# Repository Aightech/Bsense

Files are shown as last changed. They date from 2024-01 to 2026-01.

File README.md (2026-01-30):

# Bsense

Simple device to trigger audio and haptic stimuli for prenatal studies.

## Hardware

### Components

| Part | Qty | Price | Link |
|---|-----|---|---|
| Teensy 4.0/4.1 | 1 | £25 | [PJRC](https://www.pjrc.com/store/teensy40.html) |
| H-bridge (L298N) | 1 | £2 | [Amazon UK](https://www.amazon.co.uk/Driver-H-Bridge-Stepper-Controller-Arduino/dp/B07YC1GFM3) |
| LRA (VG0640001D) | 1 | £2 | [Digi-Key](https://www.digikey.co.uk/en/products/detail/vybronics-inc/VG0640001D/15220805) |
| LRA (VLV101040A) | 1 | £5 | [Digi-Key](https://www.digikey.co.uk/en/products/detail/vybronics-inc/VLV101040A/12323590) |
| STSPIN250 dev board | 1 | £15 | [MikroElektronika](https://www.mikroe.com/stspin250-click) |
| Buzzer | 1 | £5 | [Amazon UK](https://www.amazon.co.uk/dp/B096ZWCG7F) |
| GX16-5 connector | 5 | £1.50 | [Amazon UK](https://www.amazon.co.uk/gp/product/B07WPBXX57) |
| USB-B connector | 1 | £6.50 | [Amazon UK](https://www.amazon.co.uk/gp/product/B075FVGH8H/) |

**Total cost:** ~£70

### Schematic

System schematic

### Enclosure

| Model  | File |
|---|---|
| Box | [docs/box.stl](docs/box.stl) |
| Lid | [docs/lid.stl](docs/lid.stl) |

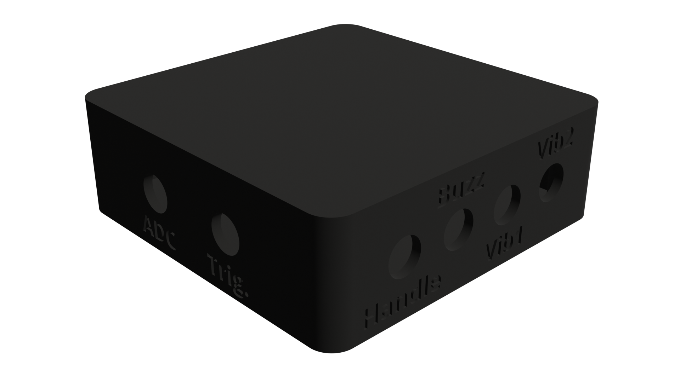
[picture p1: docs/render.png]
Rendered enclosure


## Software

### Installation

**Option 1: Download pre-built executable**

Download from [GitHub Releases](../../releases) - available for Windows, macOS, and Linux.

**Option 2: Run from source**

```bash
# Clone and setup
git clone https://github.com/your-repo/bsense.git
cd bsense/app/python

# Create virtual environment
python3 -m venv bsense_env
source bsense_env/bin/activate  # Linux/macOS
# bsense_env\Scripts\activate   # Windows

# Install dependencies
pip install -r requirements.txt

# Run
python main.py
```

CLI flags:
- `-d` - Debug mode
- `-p <port>` - Serial port (e.g., `/dev/ttyACM0` or `COM3`)
- `-f <file>` - Load experiment JSON file

### Usage

1. **Connect**: Enter serial port, click **Connect**
2. **Validate subject**: Input subject ID, click ✔
3. **Select protocol**: Choose from dropdown or browse JSON file
4. **Run**: Click ▶ to start, ‖ to pause, ■ to stop
5. **Log**: View live log; add manual annotations via input field

### Building Executables

```bash
cd app/python
./build.sh        # Linux/macOS
build.bat         # Windows
```

Or use GitHub Actions: push a tag (`git tag v1.0.0 && git push --tags`) to automatically build for all platforms.

## Experiment Protocol (JSON)

For detailed protocol documentation, see [userManualGUI.md](userManualGUI.md).

Protocols are **case-insensitive** - `"type": "sequence"` works the same as `"Type": "Sequence"`.

### Rule Types

| Type | Description | Required Fields |
|---|---|---|
| `Sequence` | Repeatable block | `Repeat`, `Content` |
| `stimulus` | Container for stimuli | `Content` (list) |
| `Delay` | Pause between stimuli | `Duration` (seconds) |
| `Dropout_sequence` | Random omissions | `Repeat`, `Number_drop`, `Content`, `Dropout_content` |
| `Randomized_sequence` | Shuffled stimuli with constraints | `Max_consecutive`, `Stimuli` |

### Stimulus Types

| Type | Description | Required Fields |
|---|---|---|
| `Vib1` | Vibration motor | `Amplitude` (0-1), `Frequency` (Hz), `Duration` (ms) |
| `Buzzer` | Audio tone | `Amplitude` (0-1), `Tone` (Hz), `Duration` (ms) |
| `BuzzVib1` | Combined | `Amplitude_vib1`, `Frequency_vib1`, `Duration_vib1`, `Amplitude_buzz`, `Tone_buzz`, `Duration_buzz` |

### Example Configs

See `app/python/config/` for examples:

| File | Description |
|---|---|
| `example_vibration.json` | Basic vibration sequence |
| `example_buzzer.json` | Buzzer tone sequence |
| `example_combined.json` | Simultaneous vib + buzzer |
| `example_dropout.json` | Sequence with random dropouts |
| `example_randomized.json` | Randomized intensity levels |

### Randomized Sequence Example

For counterbalanced experiments with multiple intensity levels:

```json
{
    "Type": "Randomized_sequence",
    "Max_consecutive": 3,
    "Delay": {"Type": "Delay", "Duration": 2, "Deviation": 0.5},
    "Stimuli": [
        {"Repeat": 20, "Label": "Low", "Content": {"Type": "Vib1", "Amplitude": 0.33, "Frequency": 170, "Duration": 100}},
        {"Repeat": 20, "Label": "Medium", "Content": {"Type": "Vib1", "Amplitude": 0.66, "Frequency": 170, "Duration": 100}},
        {"Repeat": 20, "Label": "High", "Content": {"Type": "Vib1", "Amplitude": 1.0, "Frequency": 170, "Duration": 100}}
    ]
}
```

This creates 60 stimuli (20 × 3 levels), randomized with no intensity appearing more than 3 times consecutively.

## Serial Protocol

Binary protocol at 115200 baud:

```
[0xaa] [cmd] [len] [payload...]
```

| Command | Payload (bytes) | Description |
|---|---|---|
| `'v'` | amp:1, freq:2, dur:2 | Vibration 1 |
| `'b'` | amp:1, freq:2, dur:2 | Buzzer |
| `'c'` | ampV:1, freqV:2, durV:2, ampB:1, freqB:2, durB:2 | Combined |

- Amplitude: 0-255 (0.0-1.0 scaled)
- Frequency: uint16 little-endian (0-65535 Hz)
- Duration: uint16 little-endian (milliseconds)

### MATLAB Example

```matlab
port = "COM3";
s = serialport(port, 115200);
flush(s);

START_CHAR = uint8(hex2dec('aa'));

function sendVib1(s, amp, freq, duration)
    % amp: 0-255, freq: Hz (uint16), duration: ms (uint16)
    payload = [uint8(amp), typecast(uint16(freq), 'uint8'), typecast(uint16(duration), 'uint8')];
    header = [START_CHAR; uint8('v'); uint8(numel(payload))];
    write(s, [header, payload], 'uint8');
end

function sendBuzz(s, amp, freq, duration)
    payload = [uint8(amp), typecast(uint16(freq), 'uint8'), typecast(uint16(duration), 'uint8')];
    header = [START_CHAR; uint8('b'); uint8(numel(payload))];
    write(s, [header, payload], 'uint8');
end

% Examples:
% sendVib1(s, 128, 170, 500);   % vibration: 170 Hz, 500 ms
% sendBuzz(s, 200, 1000, 250);  % buzzer: 1 kHz, 250 ms
```

## Firmware

Located in `code/teensyScript/`. Flash using Arduino IDE or PlatformIO with Teensy board support.

**Note:** LRA actuator is rated 1.8V. With 3.3V Teensy output, saturation occurs at ~60% duty cycle. Effective amplitude range is 0-77 (of 0-255).

## Technical Documentation

### Signal Generation

See [reports/siggen.md](reports/siggen.md) for details on PWM-based LRA excitation:
- Amplitude control via PWM duty cycle (0-50% maps to 0-100% user range)
- Frequency-dependent response due to LRA mechanical resonance (~230 Hz)
- Duration control in milliseconds

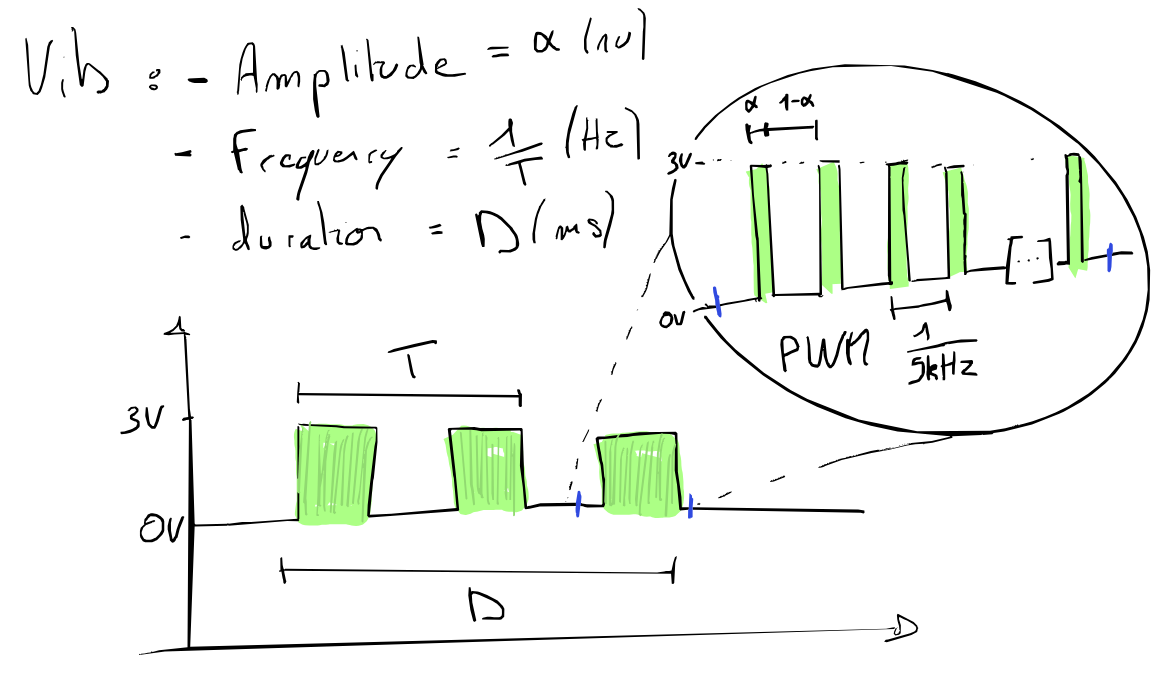
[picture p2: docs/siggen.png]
Signal generation


### LRA Simulation

The `simulation/` folder contains Python tools for modeling LRA response:

```bash
cd simulation
python cmd.py  # Interactive PWM → LRA resonator plot
```

Requires: `numpy`, `matplotlib`, optionally `scipy`

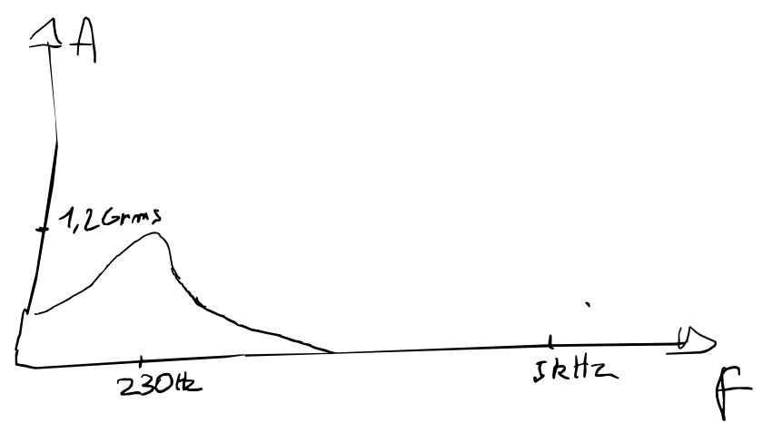
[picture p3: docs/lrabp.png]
LRA band-pass response


### Research Reports

| Report | Description |
|---|---|
| [R05jan25.md](reports/R05jan25.md) | EEG noise testing, amplitude mapping, silicone moulding |
| [siggen.md](reports/siggen.md) | Signal generation and parameter encoding |

## Running Tests

```bash
cd app/python
python -m unittest discover tests/
```

## Changelog

### v1.1.0 (2026-01-30)
- **Randomized_sequence**: New rule type for counterbalanced experiments with `Max_consecutive` constraint
- **Case-insensitive protocol**: JSON field names and types now accept any case
- **Cross-platform builds**: GitHub Actions workflow for Windows, macOS, and Linux executables
- **Improved connection handling**: Better disconnection detection and UI recovery on reconnect
- **Firmware updates**: Hardware PWM for buzzer (better high-frequency performance), 16-bit frequency support
- **Config reorganization**: Clearer example files (`example_*.json`)

### v1.0.0
- Initial release with basic vibration and buzzer control
- Sequence, Delay, and Dropout_sequence rule types

## License

MIT

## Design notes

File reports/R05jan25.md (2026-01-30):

# Report

* **Date:** January 25, 2024
* **Location:** UCL
* **Participants:** Alexis, Tabitha

## Objectives

* Investigate and mitigate EEG noise caused by LRA-related EMI.
* Test actuator amplitude mapping.
* Discuss silicone moulding setup and process.

---

## Activities

### 1. EEG Noise Testing

#### Setup

* At the hospital, Tabitha set up the EEG system with electrodes immersed in a saline solution.
* The Bsense device was configured to send periodic impulses to the LRA actuators.
* Two experimental conditions were tested:

  1. LRA actuators positioned close to the EEG electrodes (≈2–3 cm), without direct contact with the saline solution.
  2. LRA actuators in direct contact with the saline solution.

#### Observations

* **Condition 1 (LRA close, no contact):**
  No visible noise was observed on the EEG signals when the LRA actuators were activated.
* **Condition 2 (LRA in contact with saline):**
  Significant noise appeared on the EEG signals during LRA activation.

#### Hypothesis

* The observed EEG noise is likely caused by direct electrical coupling between the LRA metal casing and the conductive medium (saline / body), rather than radiated EMI.

#### Actions Taken

* **Shielding:** Although shielding did not appear to be the primary issue, the LRA metal casing was connected to a grounded shielding wire as a precautionary measure.

#### Next Steps

* Test the system on-body with the shielding connection in place.
* If noise persists, electrically isolate the LRA casing from the skin using a non-conductive layer (e.g. tape).
* If insulation resolves the issue, design a dedicated non-conductive enclosure for the LRA actuators.

---

### 2. Amplitude Mapping

#### Setup

* Connected the Bsense device to a PC via serial.
* Used a Python script to sweep PWM duty cycle values sent to the LRA actuators.
* Assessed resulting vibration amplitude using a finger as a subjective proxy.

#### Observations

* Above approximately **0.5 duty cycle**, no perceptible increase in vibration amplitude was observed.

#### Actions Taken

* Documented the signal generation and amplitude mapping process (see [LRA_Signal_Generation.md](../docs/LRA_Signal_Generation.md)).
* Created a simulation of the LRA response as a function of PWM duty cycle and excitation frequency.
  The model predicts a linear relationship between duty cycle and vibration amplitude (see figures below).

| Simulation Result                          |
| ------------------------------------------ |
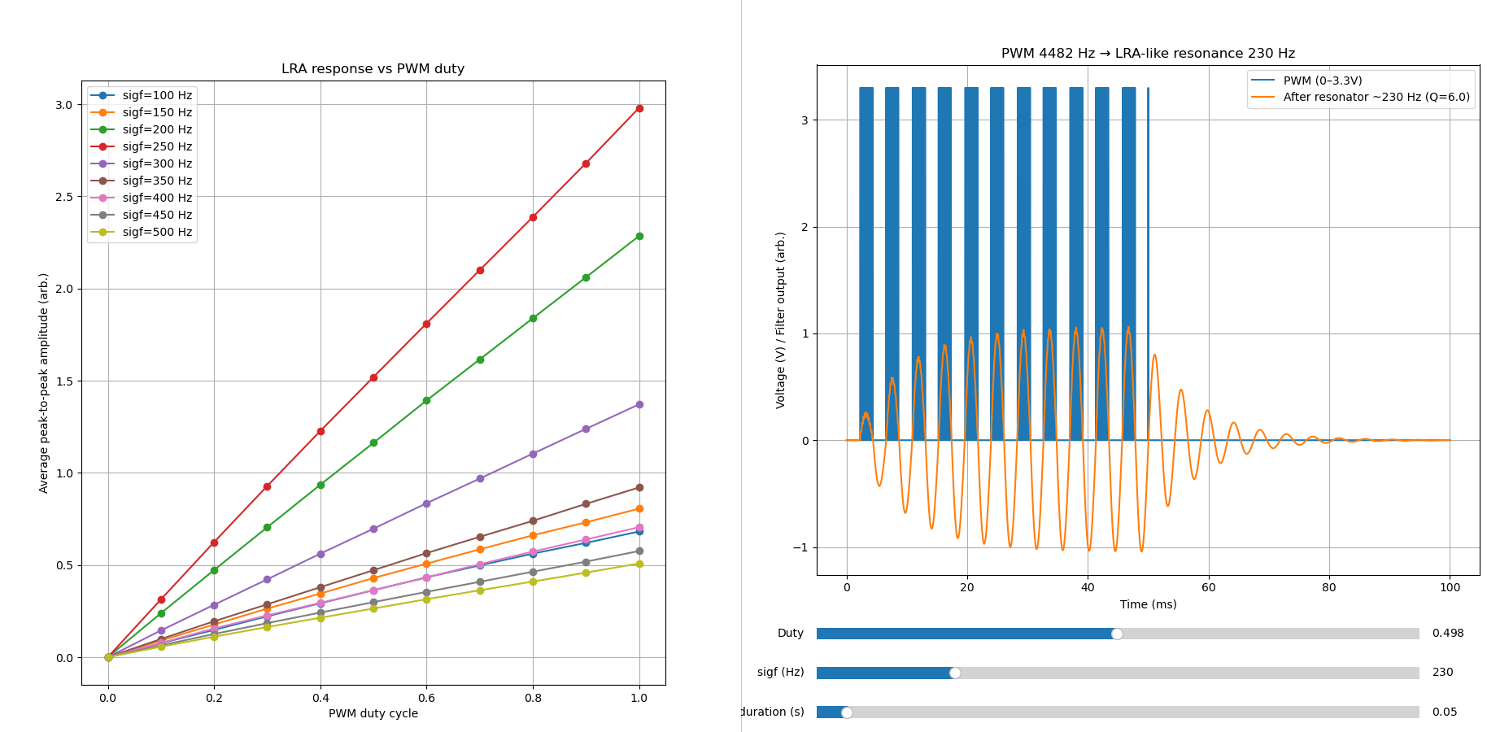
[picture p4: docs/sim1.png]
|  |
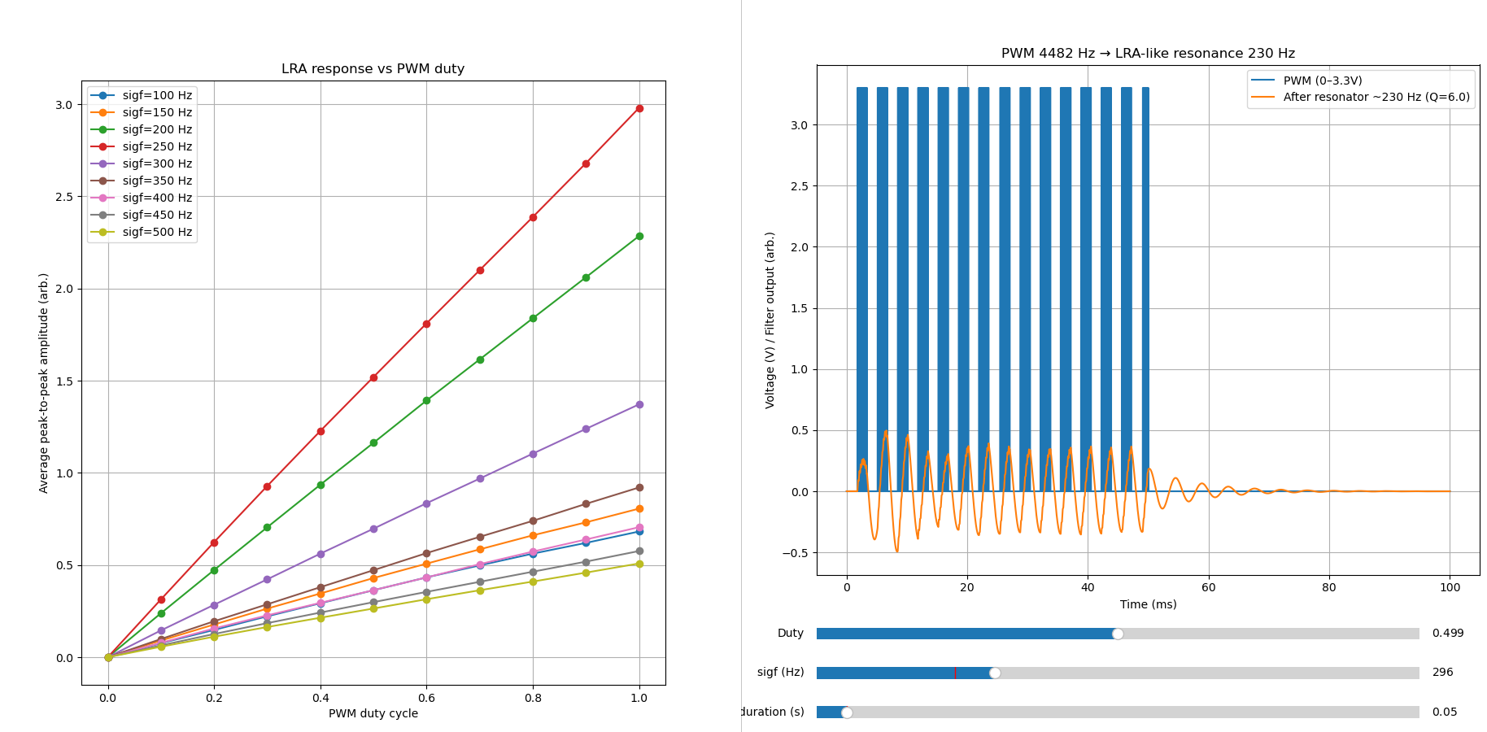
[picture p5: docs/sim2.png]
|  |
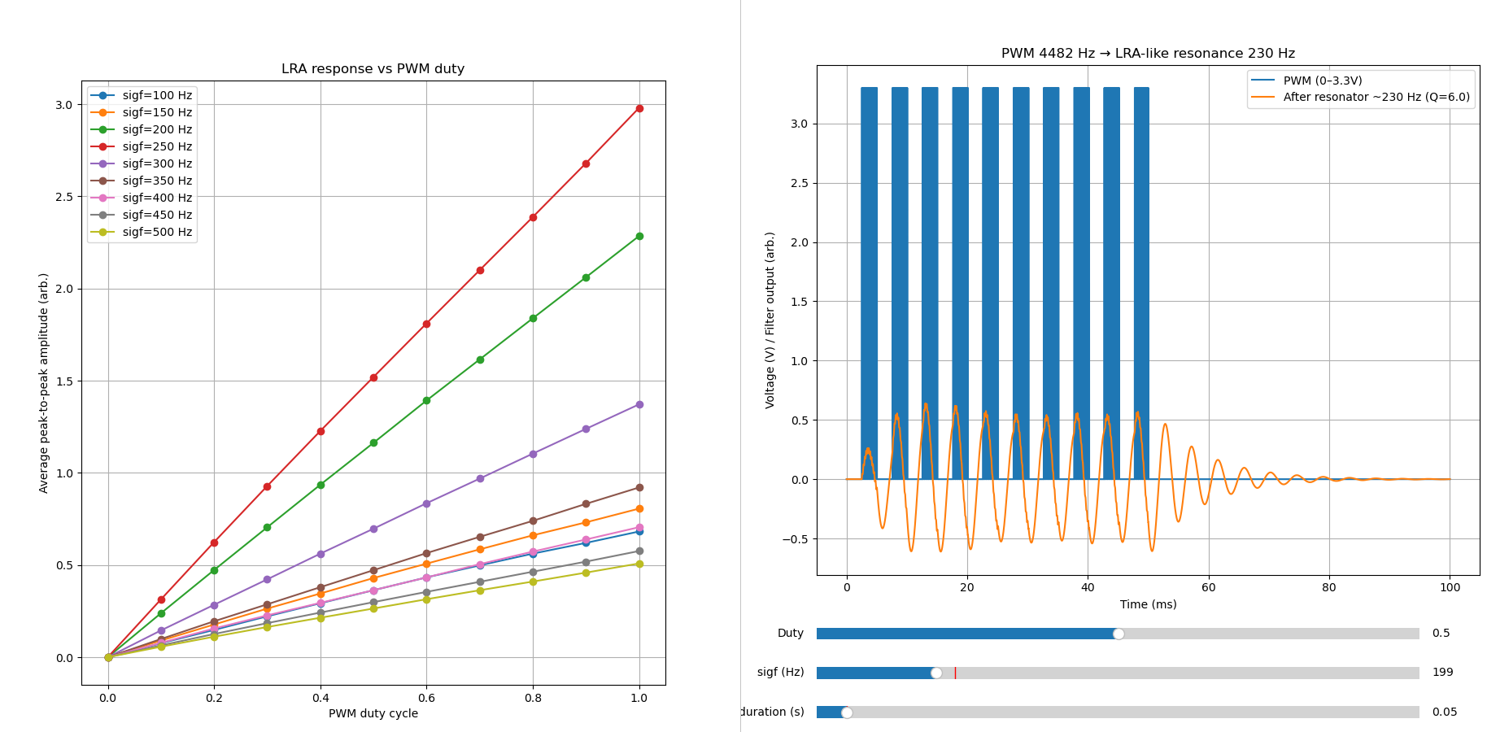
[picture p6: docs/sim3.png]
|  |

* Given the actuator’s **1.8 V RMS rating** and a **3.3 V supply**, maximum usable amplitude is expected around **~70% duty cycle**; beyond this, saturation is likely.
* Firmware was updated (no PC-side changes required) so that the full user-facing duty cycle range (0–100%) maps internally to **0–50% actuator duty cycle**.
* PWM frequency was increased to **46.875 kHz**.

#### Next Steps

* Validate the amplitude mapping using an objective measurement setup (test bench with accelerometer).

---

### 3. Silicone Moulding Discussion

Discussed the silicone moulding workflow for the grasping sensor with Tabitha.

#### Process

1. Mix silicone components A and B thoroughly (1:1 ratio).
2. *(Optional)* Apply a thin layer of release agent (e.g. Vaseline) to the 3D-printed mould to facilitate demoulding.
3. Pour the silicone mixture into the mould.
4. *(Optional)* Degas in a vacuum chamber to remove air bubbles introduced during mixing (recommended but not strictly required).
5. Allow to cure at room temperature for **4–6 hours**.
6. Carefully demould the cured silicone part.

#### Next Steps

* Purchase silicone: [Smooth-On Ecoflex 00-30](https://www.benam.co.uk/ecoflex-00-30).
* 3D print moulds for the sensor components.

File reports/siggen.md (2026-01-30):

# Tap Impulse Generation

Tap impulses are generated by driving the LRA using a parametrised PWM-based excitation signal. The impulse is fully defined by three parameters: **frequency**, **amplitude**, and **duration**.

PWM Signal

---

## Parameters

### Amplitude

* Defines the effective drive amplitude applied to the LRA.
* As the microcontroller cannot output a true analog voltage, amplitude control is implemented using **PWM (Pulse Width Modulation)**.
* The user-facing amplitude parameter is normalised to the range **0–1**.
* Internally, this value maps to a **PWM duty cycle of 0–50%**, ensuring the actuator remains within its safe operating voltage range.

---

### Frequency

* Defines the excitation frequency (in **Hz**) of the signal driving the LRA.
* Vibration strength increases as the excitation frequency approaches the LRA’s mechanical resonance (≈ **230 Hz**).
* Frequencies far from resonance result in significantly reduced vibration amplitude due to the LRA’s band-pass mechanical response.

---

### Duration

* Defines the length of the impulse in **milliseconds**.
* The actuator is driven continuously at the specified frequency and amplitude for the duration of the impulse.

LRA band-pass response

---

## Parameter Encoding

Each parameter is encoded using **1 byte (8 bits)**, allowing compact transmission and deterministic decoding:

* **Frequency:**

  * Range: **0–255 Hz**
  * Resolution: **1 Hz per step**

* **Amplitude:**

  * Range: **0–1 (normalised)**
  * Resolution: **1 / 255 ≈ 0.00392 per step**

* **Duration:**

  * Range: **0–255 ms**
  * Resolution: **1 ms per step**

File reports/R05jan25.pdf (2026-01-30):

# Report

Date: January 25, 2024
Location: UCL
Participants: Alexis, Tabitha

# Objectives

Investigate and mitigate EEG noise caused by LRA-related EMI. Test actuator amplitude mapping.
Discuss silicone moulding setup and process.

# Activities

## 1. EEG Noise Testing

### Setup

At the hospital, Tabitha set up the EEG system with electrodes immersed in a saline solution. The Bsense device was configured to send periodic impulses to the LRA actuators.
Two experimental conditions were tested:
i. LRA actuators positioned close to the EEG electrodes (≈2–3 cm), without direct contact with the saline solution.
ii. LRA actuators in direct contact with the saline solution.

### Observations

Condition 1 (LRA close, no contact):
No visible noise was observed on the EEG signals when the LRA actuators were activated. Condition 2 (LRA in contact with saline):
Significant noise appeared on the EEG signals during LRA activation.

### Hypothesis

The observed EEG noise is likely caused by direct electrical coupling between the LRA metal casing and the conductive medium (saline / body), rather than radiated EMI.

### Actions Taken

Shielding: Although shielding did not appear to be the primary issue, the LRA metal casing was connected to a grounded shielding wire as a precautionary measure.

### Next Steps

Test the system on-body with the shielding connection in place.
If noise persists, electrically isolate the LRA casing from the skin using a non-conductive layer (e.g. tape).
If insulation resolves the issue, design a dedicated non-conductive enclosure for the LRA actuators.

## 2. Amplitude Mapping

### Setup

Connected the Bsense device to a PC via serial.
Used a Python script to sweep PWM duty cycle values sent to the LRA actuators. Assessed resulting vibration amplitude using a finger as a subjective proxy.

### Observations

Above approximately 0.5 duty cycle, no perceptible increase in vibration amplitude was observed.

### Actions Taken

Documented the signal generation and amplitude mapping process (see LRA_Signal_Generation.md).
Created a simulation of the LRA response as a function of PWM duty cycle and excitation frequency.
The model predicts a linear relationship between duty cycle and vibration amplitude (see figures below).

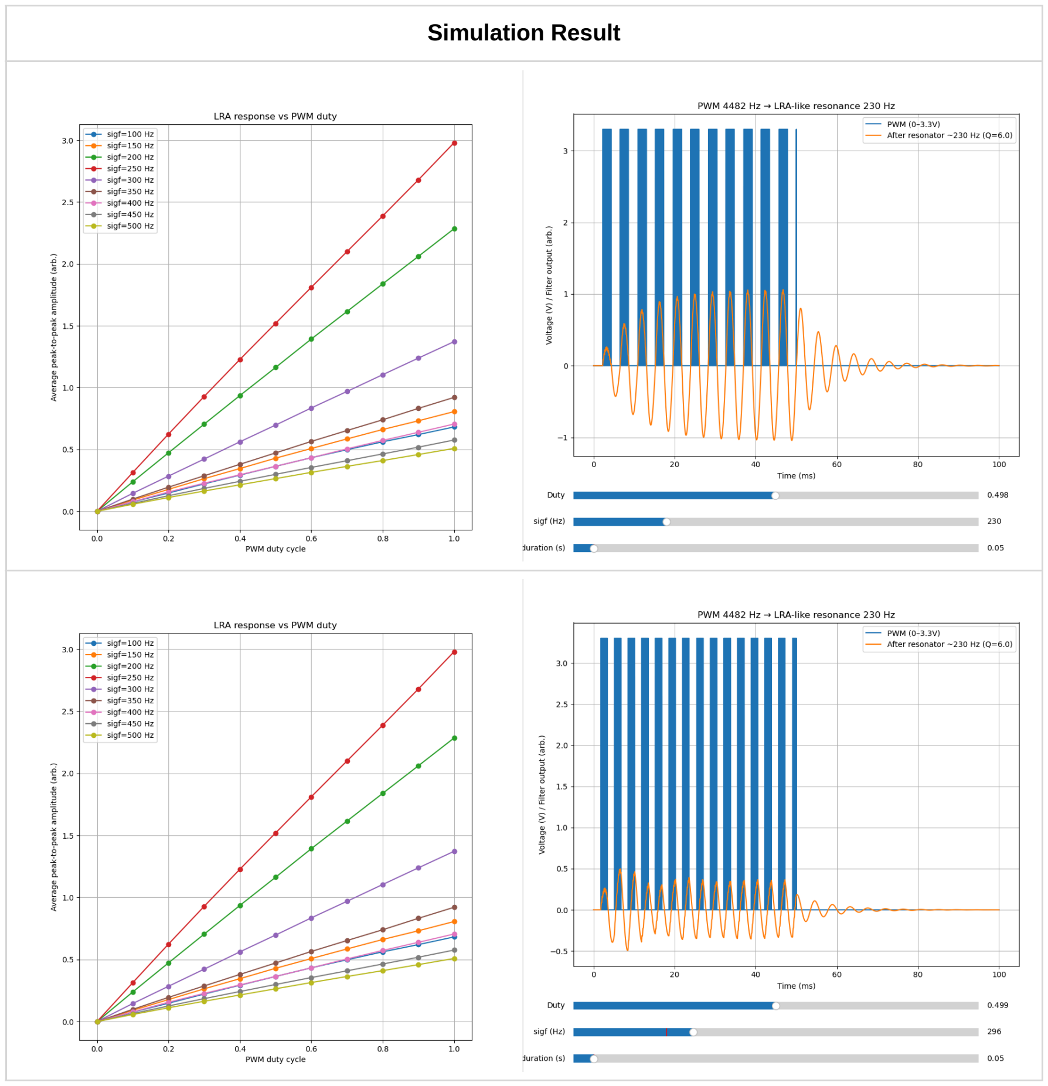
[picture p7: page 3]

Simulation Result

Simulation Result

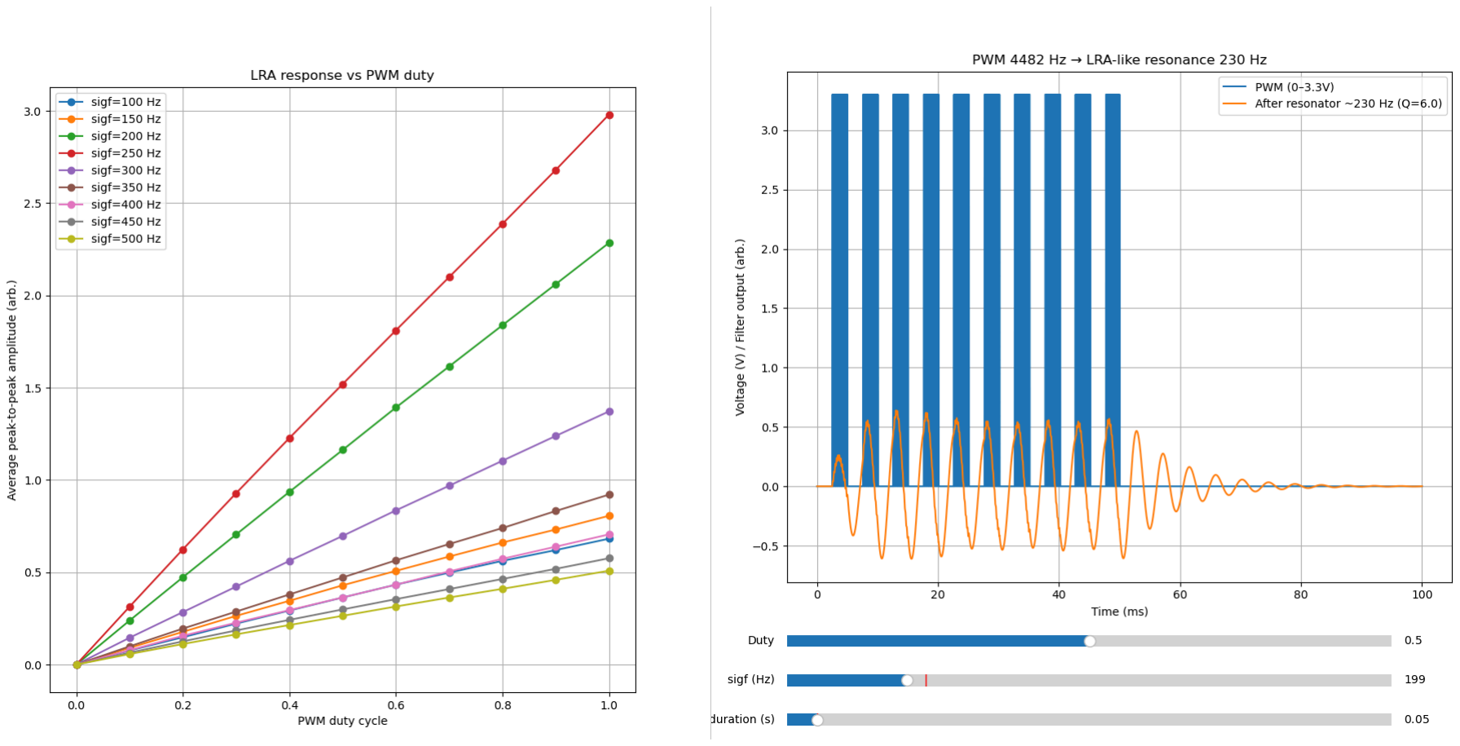
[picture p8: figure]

Given the actuator’s 1.8 V RMS rating and a 3.3 V supply, maximum usable amplitude is expected around ~70% duty cycle; beyond this, saturation is likely.
Firmware was updated (no PC-side changes required) so that the full user-facing duty cycle range (0–100%) maps internally to 0–50% actuator duty cycle.
PWM frequency was increased to 46.875 kHz.

### Next Steps

Validate the amplitude mapping using an objective measurement setup (test bench with accelerometer).

## 3. Silicone Moulding Discussion

Discussed the silicone moulding workflow for the grasping sensor with Tabitha.

### Process

1. Mix silicone components A and B thoroughly (1:1 ratio).
2. (Optional) Apply a thin layer of release agent (e.g. Vaseline) to the 3D-printed mould to facilitate demoulding.
3. Pour the silicone mixture into the mould.

4. (Optional) Degas in a vacuum chamber to remove air bubbles introduced during mixing (recommended but not strictly required).
5. Allow to cure at room temperature for 4–6 hours.
6. Carefully demould the cured silicone part.

### Next Steps

Purchase silicone: Smooth-On Ecoflex 00-30. (https://www.benam.co.uk/ecoflex-00-30) 3D print moulds for the sensor components.

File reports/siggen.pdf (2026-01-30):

# Tap Impulse Generation

Tap impulses are generated by driving the LRA using a parametrised PWM-based excitation signal. The impulse is fully defined by three parameters: frequency, amplitude, and duration.

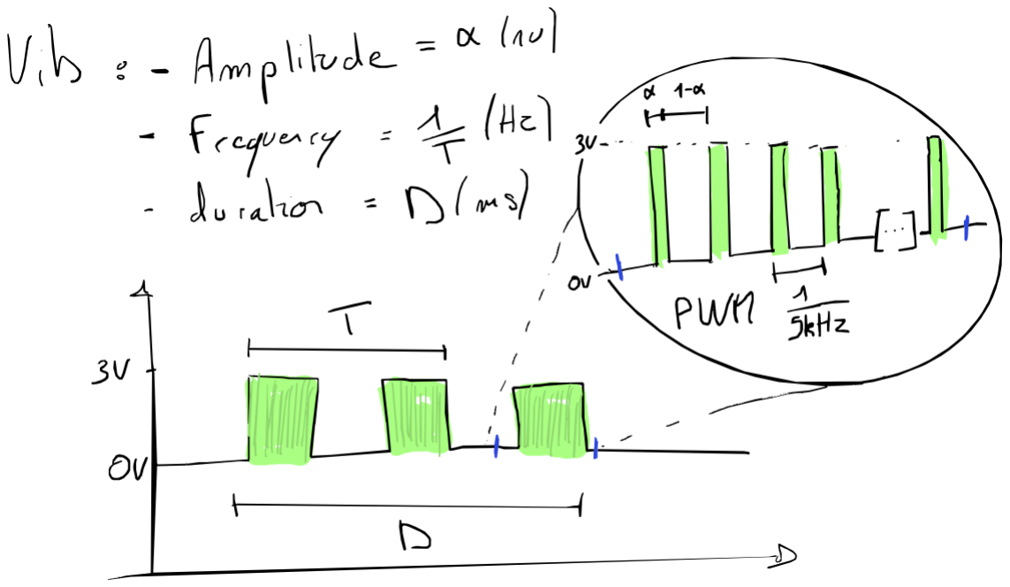
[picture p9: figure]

# Parameters

## Amplitude

Defines the effective drive amplitude applied to the LRA.
As the microcontroller cannot output a true analog voltage, amplitude control is implemented using PWM (Pulse Width Modulation).
The user-facing amplitude parameter is normalised to the range 0–1.
Internally, this value maps to a PWM duty cycle of 0–50%, ensuring the actuator remains within its safe operating voltage range.

## Frequency

Defines the excitation frequency (in Hz) of the signal driving the LRA.
Vibration strength increases as the excitation frequency approaches the LRA’s mechanical resonance (≈ 230 Hz).
Frequencies far from resonance result in significantly reduced vibration amplitude due to the LRA’s band-pass mechanical response.

## Duration

Defines the length of the impulse in milliseconds.
The actuator is driven continuously at the specified frequency and amplitude for the duration of the impulse.

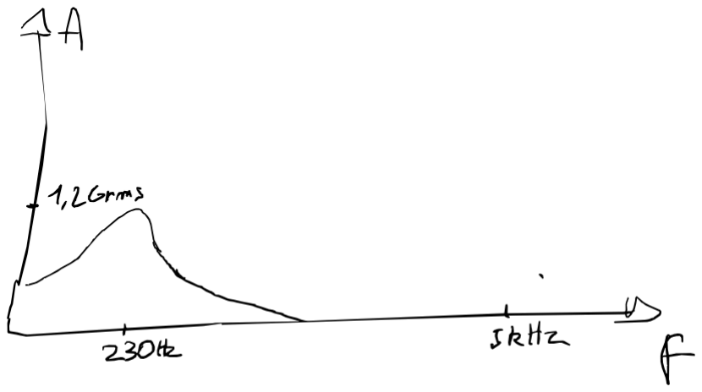
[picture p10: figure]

# Parameter Encoding

Each parameter is encoded using 1 byte (8 bits), allowing compact transmission and deterministic decoding:

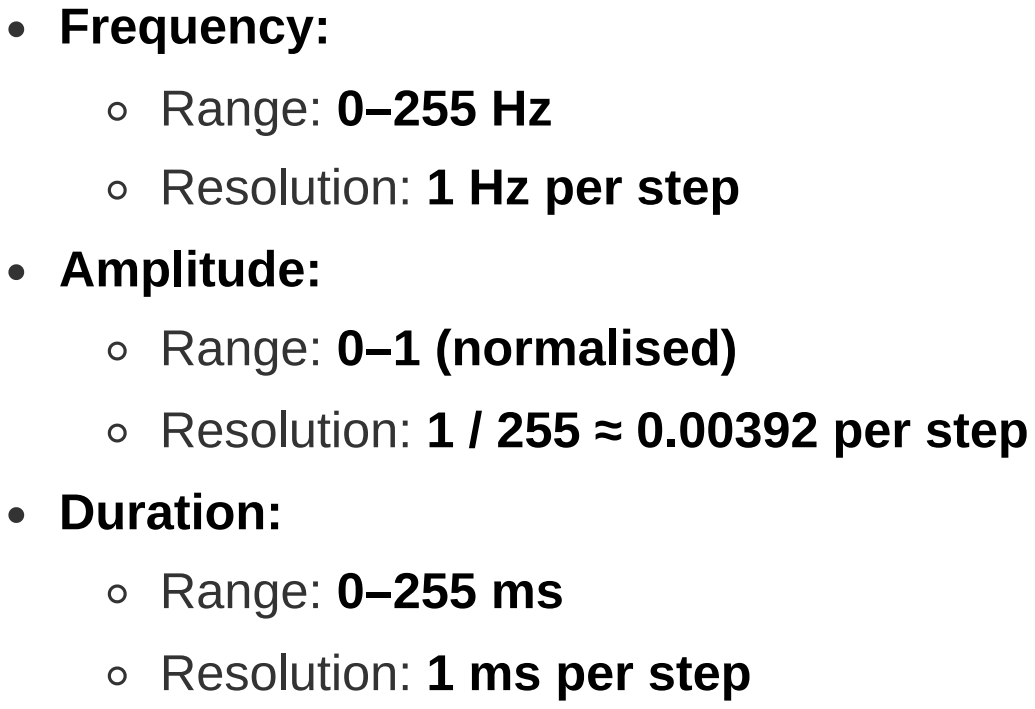
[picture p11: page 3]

Frequency:
Range: 0–255 Hz
Resolution: 1 Hz per step
Amplitude:
Range: 0–1 (normalised)
Resolution: 1 / 255 ≈ 0.00392 per step
Duration:
Range: 0–255 ms
Resolution: 1 ms per step

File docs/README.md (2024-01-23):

# Bsense Project

This project, Bsense, is designed to provide a comprehensive solution for [describe the main purpose of the project, e.g., 'multi-sensory feedback experiments'].

## Installation

To install the necessary dependencies, run:

```bash
pip install -r requirements.txt
```

## Usage

Describe how to use the application, including any necessary setup steps.

## Contributing

Contributions to the Bsense project are welcome. Please follow these steps to contribute:

1. Fork the repository.
2. Create a new branch for your feature.
3. Add your changes and commit them.
4. Push to your branch and submit a pull request.

## License

[Specify the license or state 'No License'.]

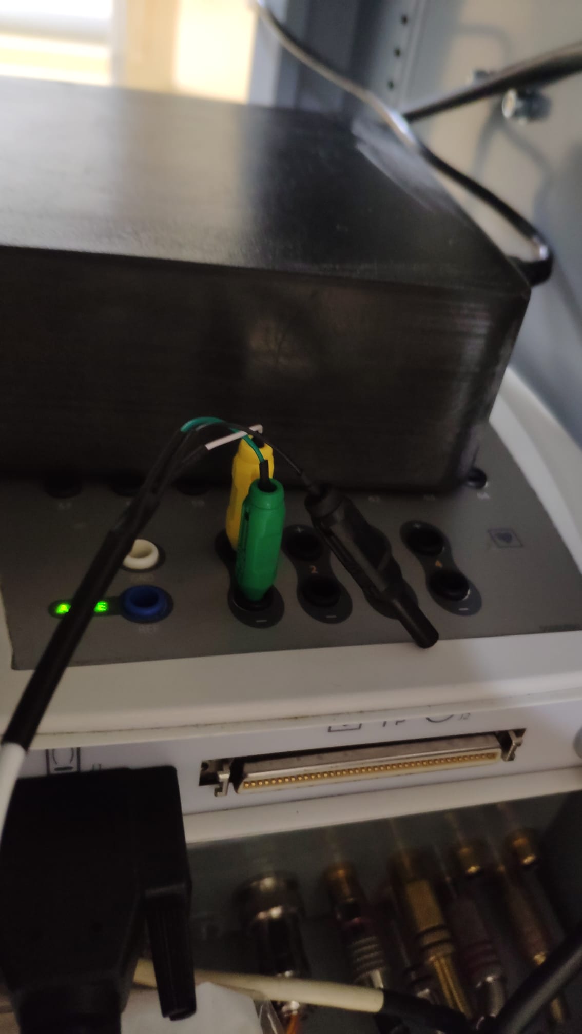
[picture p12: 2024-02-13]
docs/picADCconn.jpeg

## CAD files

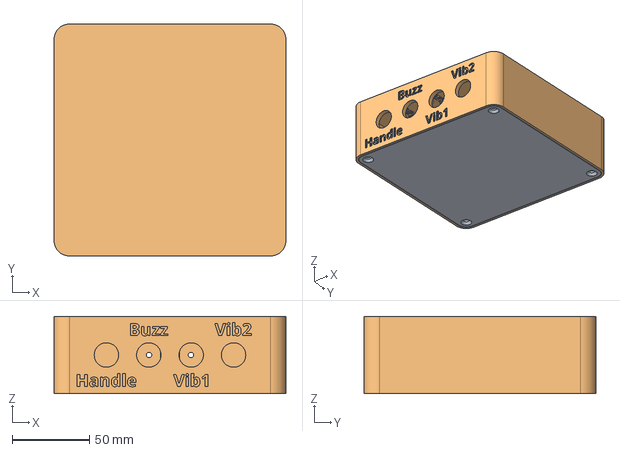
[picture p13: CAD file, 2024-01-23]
resources/cad/Assembly 1.step
150.0 x 150.0 x 50.0 mm

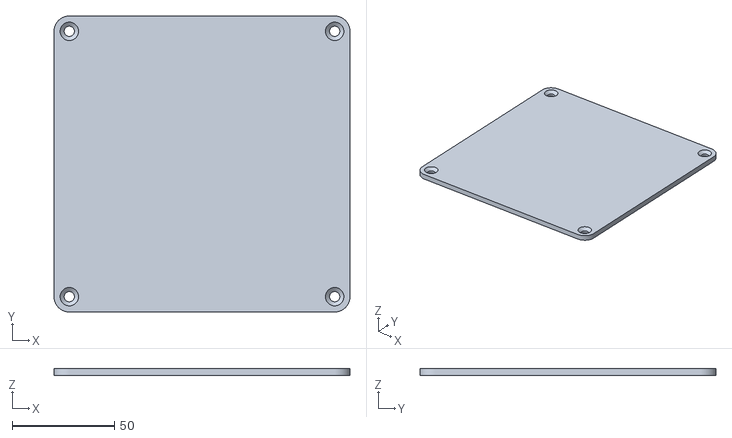
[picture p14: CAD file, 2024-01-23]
resources/cad/box_lid(1).stl
145.0 x 145.0 x 3.50

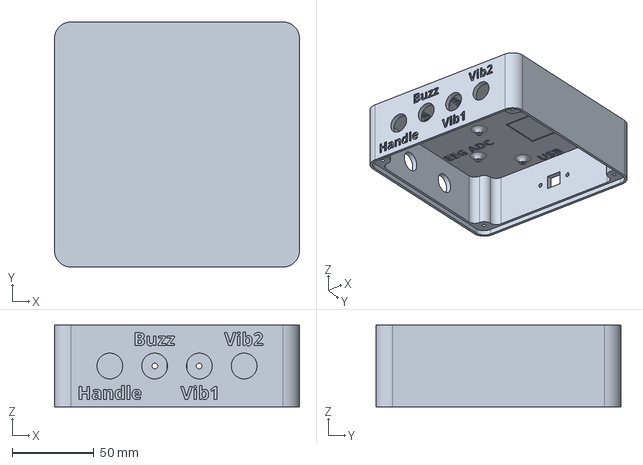
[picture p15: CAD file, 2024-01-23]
resources/cad/box.step
150.0 x 150.0 x 50.0 mm

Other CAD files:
resources/cad/box_lid.step

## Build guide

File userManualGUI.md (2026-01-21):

# Bsense GUI User Documentation

## Overview

Bsense GUI, is a Python-based graphical user interface for conducting experiments with the Bsense device. Version 1.0 of this software allows users to connect to devices, select and customize experiments, and manage experiment logs and settings. The GUI is designed to be user-friendly and intuitive, allowing for easy setup and execution of experiments.

## Features

### Connection Settings
- **Device Connection:** Allows users to specify the device connection port (e.g., COM3) and establish a connection to the device. (Note: The device must be connected to the computer via USB. On Windows, you can find the device port in the Device Manager under "Ports (COM & LPT)".)
- **User Validation:** Users have to enter a subject name/ID and validate it before starting an experiment. The log file will be saved with the subject name as the filename.

### Experiment Configuration
- Predefined experiments: Includes a set of predefined experiments which can be selected via a dropdown menu.
- Custom experiments: Users can load custom experiments by selecting a JSON file that defines the experiment parameters. You have to select "Experiment Custom" in the type of experiement and then select the file using the "Browse" button. (see [Writing Your Own Experiment Configuration File](#writing-your-own-experiment-configuration-file) for more details on the JSON file format)

### Experiment Controls

- **Start (GO):** Begins the execution of the selected experiment.
- **Pause:** Temporarily halts the experiment.
- **Stop:** Terminates the experiment.

### Log Management

- **Experiment Log:** Displays a real-time log of the experiment events and actions. Users can also add custom log entries via the "Add Log" button.

### Closing the Application

- Ensures proper shutdown by closing the connection to the device and saving the log file if it was opened.

## Usage

1. **Start the Application:** Launch the GUI application.
2. **Connect to Device:** Enter the device port in the connection section and click "Connect".
3. **Validate User:** Enter a subject name and click the validate button (checkmark icon).
4. **Select Experiment:** Choose an experiment from the dropdown menu or load a custom experiment using the "Browse" button.
5. **Start Experiment:** Click the "GO" button to start the experiment. Use "PAUSE" and "STOP" buttons to control the experiment flow.
6. **Add Log Entries:** Optionally, add custom log entries during the experiment.
7. **Close Application:** Close the application window or use the "STOP" button to ensure a proper shutdown.

# Writing Your Own Experiment Configuration File

## Overview

The experiment configuration file is a JSON document that defines the structure and behavior of an experiment. It allows for the specification of sequences, stimuli, delays, and dropout sequences to create complex, repeatable experimental conditions.

## Types

### Sequence

A sequence is a collection of stimuli and delays that are executed in order. It can contain other sequences, allowing for nested structures.

- **Type**: Must be `"Sequence"`.
- **Repeat**: How many times the sequence repeats.
- **Content**: An array of `stimulus` and `Delay` objects.

### Stimulus

Defines a stimulus event, such as a vibration or a buzzer sound.

- **Type**: Must be `"stimulus"`.
- **Content**: An array of objects detailing the stimulus types (`Vib1`, `Vib2`, `Buzzer`) and their properties.

#### Properties

- **Amplitude**: The intensity of the stimulus.
- **Deviation**: Allows for random variation in the amplitude.
- **Type**: The type of stimulus (`Vib1`, `Vib2`, `Buzzer`).
- **Tone** (optional for `Buzzer`): The tone frequency.
- **Duration** (optional for `Buzzer`): How long the buzzer sounds.

### Delay

Specifies a pause or delay between stimuli within a sequence.

- **Type**: Must be `"Delay"`.
- **Duration**: The length of the delay.
- **Deviation**: Allows for random variation in the duration.

### Dropout_sequence

Similar to a sequence but with the ability to randomly omit certain repetitions, replacing them with alternative content.

- **Type**: Must be `"Dropout_sequence"`.
- **Repeat**: The total number of times the sequence should be attempted.
- **Number_drop**: How many of those repetitions to replace.
- **Content**: The normal sequence content.
- **Dropout_content**: The content to use when a repetition is dropped.

### Randomized_sequence

Creates a randomized sequence of stimuli from multiple intensity levels, ensuring no single intensity repeats more than a specified number of times consecutively. Useful for experiments requiring counterbalanced stimulus presentation.

- **Type**: Must be `"Randomized_sequence"`.
- **Max_consecutive**: Maximum times any single stimulus type can appear consecutively (e.g., 3 means no more than 3 in a row).
- **Stimuli**: Array of stimulus definitions, each with:
  - **Repeat**: How many times this stimulus appears in the total sequence.
  - **Label**: (Optional) A label for logging/display (e.g., "33%", "Low").
  - **Content**: The stimulus definition (same format as stimulus Content items).
- **Delay**: (Optional) A Delay object inserted between each stimulus.

#### Example: Three intensity levels, 20 repeats each

```json
{
  "Type": "Randomized_sequence",
  "Max_consecutive": 3,
  "Delay": {"Type": "Delay", "Duration": 2, "Deviation": 0.5},
  "Stimuli": [
    {
      "Repeat": 20,
      "Label": "33%",
      "Content": {"Type": "Vib1", "Amplitude": 0.33, "Frequency": 170, "Duration": 100}
    },
    {
      "Repeat": 20,
      "Label": "66%",
      "Content": {"Type": "Vib1", "Amplitude": 0.66, "Frequency": 170, "Duration": 100}
    },
    {
      "Repeat": 20,
      "Label": "100%",
      "Content": {"Type": "Vib1", "Amplitude": 1.0, "Frequency": 170, "Duration": 100}
    }
  ]
}
```

This creates 60 total stimulations (20 × 3 intensities), randomized with no intensity appearing more than 3 times in a row, with a 2±0.5 second delay between each.

## Example Configuration

```json
{
  "Type": "Sequence",
  "Repeat": 1,
  "Content": [
    {
      "Type": "Sequence",
      "Repeat": 15,
      "Content": [
        {
          "Type": "stimulus",
          "Content": [
            {
              "Type": "Vib2",
              "Amplitude": 1,
              "Deviation": 0
            },
            {
              "Type": "Buzzer",
              "Amplitude": 1,
              "Deviation": 0
            }
          ]
        },
        {
          "Type": "Delay",
          "Duration": 5,
          "Deviation": 0
        }
      ]
    },
    {
      "Type": "Dropout_sequence",
      "Repeat": 5,
      "Number_drop": 1,
      "Content": [
        {
          "Type": "stimulus",
          "Content": [
            {
              "Type": "Vib2",
              "Amplitude": 1,
              "Deviation": 0
            }
          ]
        },
        {
          "Type": "Delay",
          "Duration": 5,
          "Deviation": 0
        }
      ],
      "Dropout_content": [
        {
          "Type": "Delay",
          "Duration": 5,
          "Deviation": 0
        }
      ]
    }
  ]
}
```

## Tips for Writing Configuration Files

- **Case-insensitive**: All field names and type values are case-insensitive. You can write `"Type": "Sequence"`, `"type": "sequence"`, or even `"TYPE": "SEQUENCE"` - they all work the same.
- Repeat values allow for repeating sequences or stimuli, creating complex experimental patterns without duplicating definitions.
- Utilize Deviation to introduce variability into your experiment, making it less predictable and more realistic.
- Dropout_sequence allows for the creation of dynamic experiments where certain sequences can be randomly omitted, introducing unpredictability and variability.

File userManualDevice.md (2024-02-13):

# Bsense device User Documentation
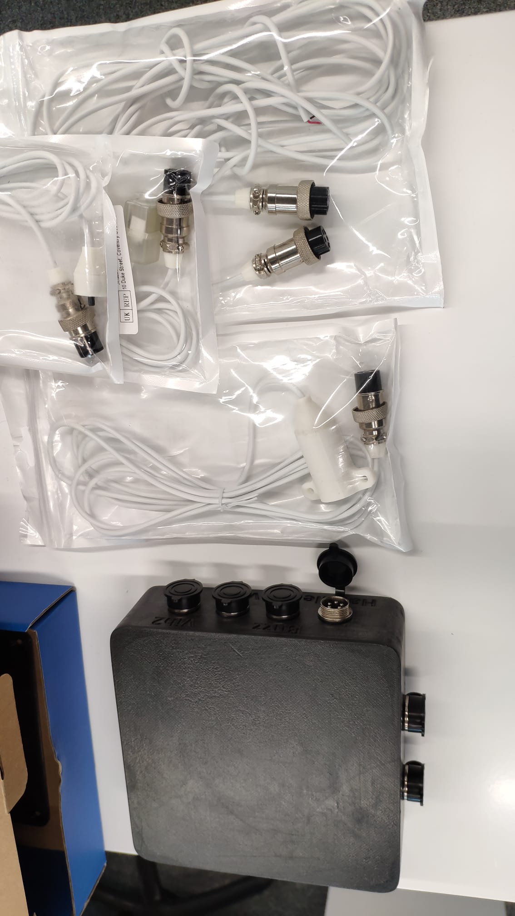
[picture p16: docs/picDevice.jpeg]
Bsense


## Introduction
Bsense is a simple device to trigger audio and haptic stimulus for prenatanal studies. The device is composed of:
- An Arduino Mega 2560
- An H-brige -  L298N
- DC driver - STspin250
- 2x 9V batteries
- Accessories:
    - Pressure handle:
        - Silicone holow handle
        - Pressure sensor 
    - Buzzer - Jopto DC 3.3-5V Passive Low Level Trigger
    - Haptic stimulator v1:
        - LRA - VG0640001D
    - Haptic stimulator v2:
        - LRA - VLV101040A

# Connection
## PC - Device
The device is connected to the computer via USB. The device is powered by 2x 9V batteries.

## Device - Accessories
The device is connected to the accessories via the GX16-5 Connectors in the following way:
- **Handle**: Connected to the pressure sensor handle
- **Buzzer**: Connected to the buzzer
- **Vib1**: Currently not used
- **Vib2**: Connected to the hapic stimulator v1 or v2

## Device - Auxilliary output
The device has 2 auxilliary outputs:
- **ADC**: The pressure sensor analog output is directly connected to this connector. It can be used to monitor the pressure sensor output with an external Analog to Digital Converter. Here a plugging example picture:
ADC
- **Trigger**: The trigger output is a 5V signal that is outputed when a stimulus is given to the subject. It can be used to synchronize the device with other devices.

## Diagram

Diagram

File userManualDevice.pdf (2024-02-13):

# Bsense device User Documentation

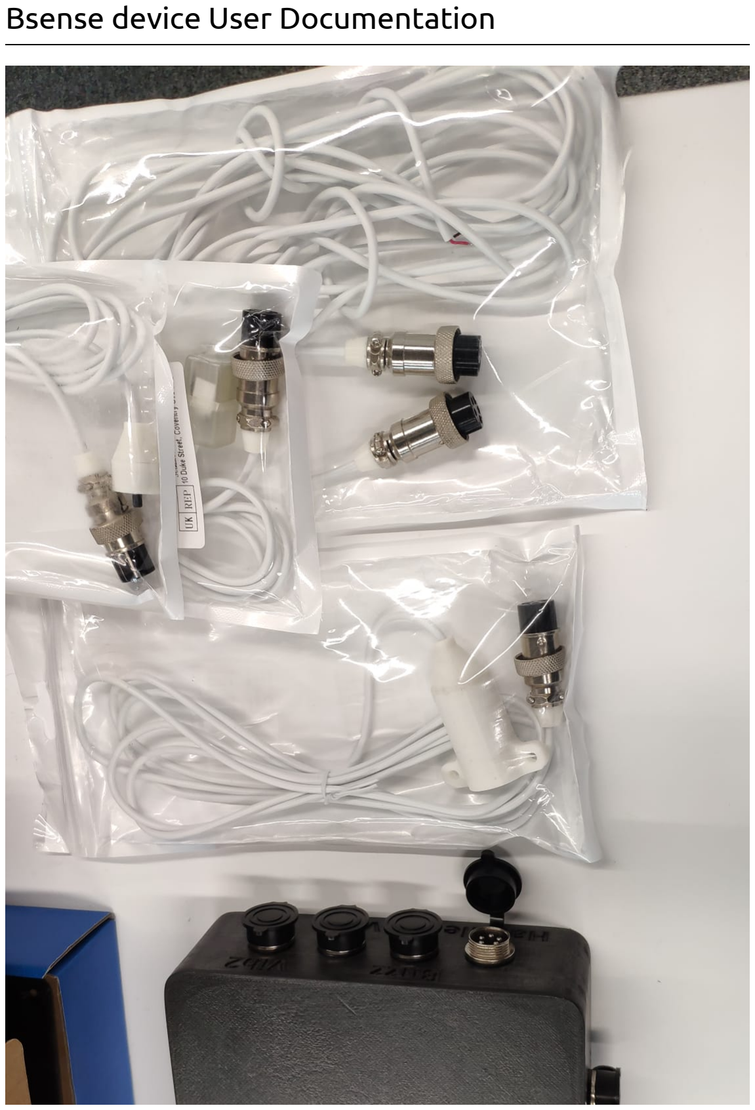
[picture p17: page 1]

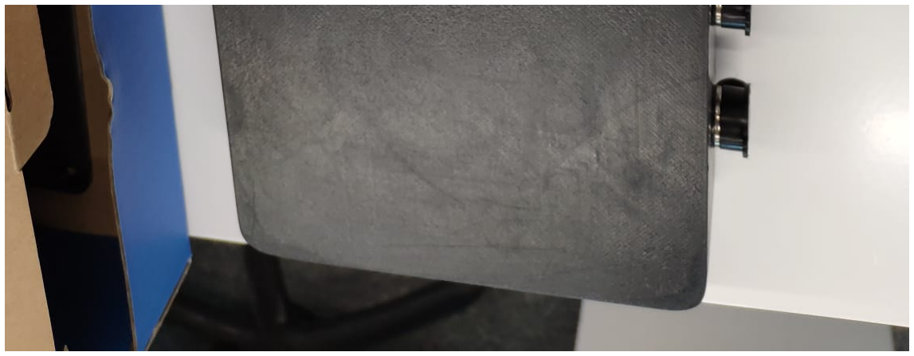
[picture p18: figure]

## Introduction

Bsense is a simple device to trigger audio and haptic stimulus for prenatanal studies. The device is composed of:

An Arduino Mega 2560
An H-brige - L298N
DC driver - STspin250
2x 9V batteries
Accessories:
Pressure handle:
Silicone holow handle
Pressure sensor
Buzzer - Jopto DC 3.3-5V Passive Low Level Trigger Haptic stimulator v1:
LRA - VG0640001D
Haptic stimulator v2:
LRA - VLV101040A

# Connection

## PC - Device

The device is connected to the computer via USB. The device is powered by 2x 9V batteries.

## Device - Accessories

The device is connected to the accessories via the GX16-5 Connectors in the following way:

Handle: Connected to the pressure sensor handle
Buzzer: Connected to the buzzer
Vib1: Currently not used
Vib2: Connected to the hapic stimulator v1 or v2

## Device - Auxilliary output

## Diagram

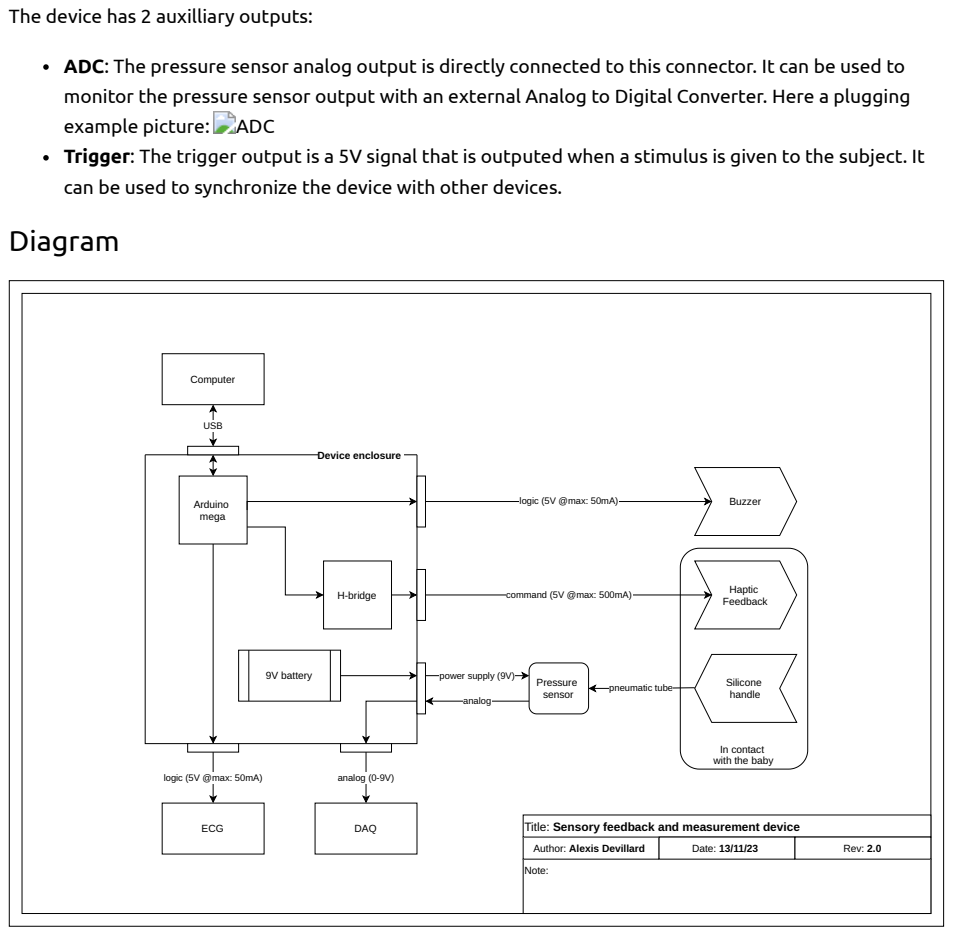
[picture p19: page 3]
example picture:; ADC; Device enclosure; H-bridge; Arduino mega; 9V battery; Buzzer; Haptic Feedback; Silicone handle; USB; Computer; ECG; DAQ; analog; Pressure sensor; logic (5V @max: 50mA); command (5V @max: 500mA); power supply (9V); analog (0-9V); pneumatic tube; Note:; Date: 13/11/23; Rev: 2.0

The device has 2 auxilliary outputs:

ADC: The pressure sensor analog output is directly connected to this connector. It can be used to
monitor the pressure sensor output with an external Analog to Digital Converter. Here a plugging
Trigger: The trigger output is a 5V signal that is outputed when a stimulus is given to the subject. It
can be used to synchronize the device with other devices.

In contact with the baby

Title: Sensory feedback and measurement device

Author: Alexis Devillard

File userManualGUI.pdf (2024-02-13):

# Bsense GUI User Documentation

## Overview

Bsense GUI, is a Python-based graphical user interface for conducting experiments with the Bsense device. Version 1.0 of this software allows users to connect to devices, select and customize experiments, and manage experiment logs and settings. The GUI is designed to be user-friendly and intuitive, allowing for easy setup and execution of experiments.

## Features

Connection Settings

Device Connection: Allows users to specify the device connection port (e.g., COM3) and establish a connection to the device. (Note: The device must be connected to the computer via USB. On Windows, you can find the device port in the Device Manager under "Ports (COM & LPT)".)
User Validation: Users have to enter a subject name/ID and validate it before starting an experiment. The log file will be saved with the subject name as the filename.

Experiment Configuration

Predefined experiments: Includes a set of predefined experiments which can be selected via a dropdown menu.
Custom experiments: Users can load custom experiments by selecting a JSON file that defines the experiment parameters. You have to select the file using the "Browse" button. (see Writing Your Own Experiment Configuration File for more details on the JSON file format)

Experiment Controls

Start (GO): Begins the execution of the selected experiment.
Pause: Temporarily halts the experiment.
Stop: Terminates the experiment.

Log Management

Experiment Log: Displays a real-time log of the experiment events and actions. Users can also add custom log entries via the "Add Log" button.

Closing the Application

Ensures proper shutdown by closing the connection to the device and saving the log file if it was opened.

## Usage

1. Start the Application: Launch the GUI application.
2. Connect to Device: Enter the device port in the connection section and click "Connect".
3. Validate User: Enter a subject name and click the validate button (checkmark icon).

4. Select Experiment: Choose an experiment from the dropdown menu or load a custom experiment using the "Browse" button.
5. Start Experiment: Click the "GO" button to start the experiment. Use "PAUSE" and "STOP" buttons to control the experiment flow.
6. Add Log Entries: Optionally, add custom log entries during the experiment.
7. Close Application: Close the application window or use the "STOP" button to ensure a proper shutdown.

# Writing Your Own Experiment Configuration File

## Overview

The experiment configuration file is a JSON document that defines the structure and behavior of an experiment. It allows for the specification of sequences, stimuli, delays, and dropout sequences to create complex, repeatable experimental conditions.

## Types

Sequence

A sequence is a collection of stimuli and delays that are executed in order. It can contain other sequences, allowing for nested structures.

Type: Must be "Sequence".
Repeat: How many times the sequence repeats. Content: An array of stimulus and Delay objects.

Stimulus

Defines a stimulus event, such as a vibration or a buzzer sound.

Type: Must be "stimulus".
Content: An array of objects detailing the stimulus types (Vib1, Vib2, Buzzer) and their properties.

Properties

Amplitude: The intensity of the stimulus.
Deviation: Allows for random variation in the amplitude. Type: The type of stimulus (Vib1, Vib2, Buzzer).
Tone (optional for Buzzer): The tone frequency.
Duration (optional for Buzzer): How long the buzzer sounds.

Delay

Specifies a pause or delay between stimuli within a sequence.

Type: Must be "Delay".
Duration: The length of the delay.
Deviation: Allows for random variation in the duration.

Dropout_sequence

Similar to a sequence but with the ability to randomly omit certain repetitions, replacing them with alternative content.

Type: Must be "Dropout_sequence".
Repeat: The total number of times the sequence should be attempted. Number_drop: How many of those repetitions to replace.
Content: The normal sequence content.
Dropout_content: The content to use when a repetition is dropped.

## Example Configuration

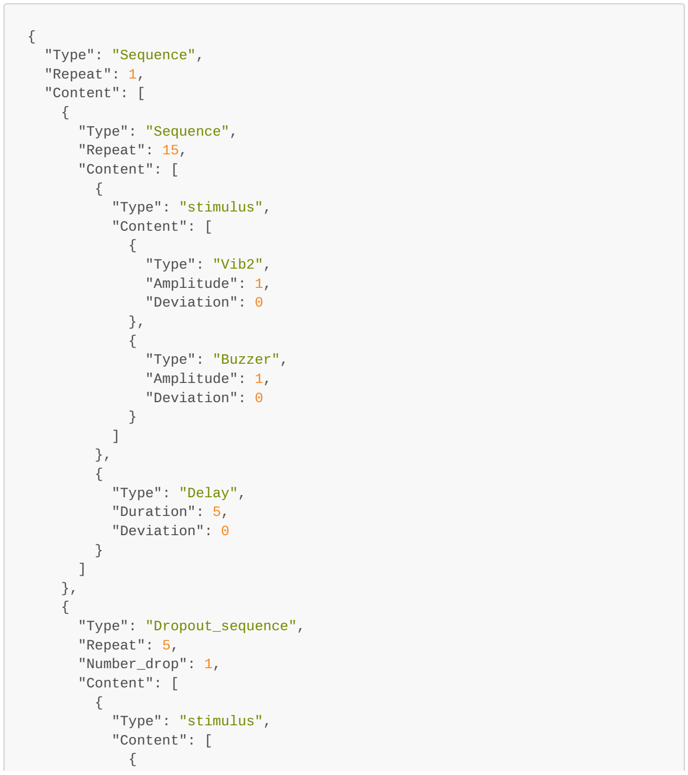
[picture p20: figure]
"Type": "Sequence", "Repeat": 1, "Content": [ {; "Type": "Sequence", "Repeat": 15, "Content": [ {; "Type": "stimulus", "Content": [ {; "Type": "Vib2", "Amplitude": 1, "Deviation": 0; "Type": "Buzzer", "Amplitude": 1, "Deviation": 0; "Type": "Delay", "Duration": 5, "Deviation": 0; "Type": "Dropout_sequence", "Repeat": 5, "Number_drop": 1, "Content": [ {

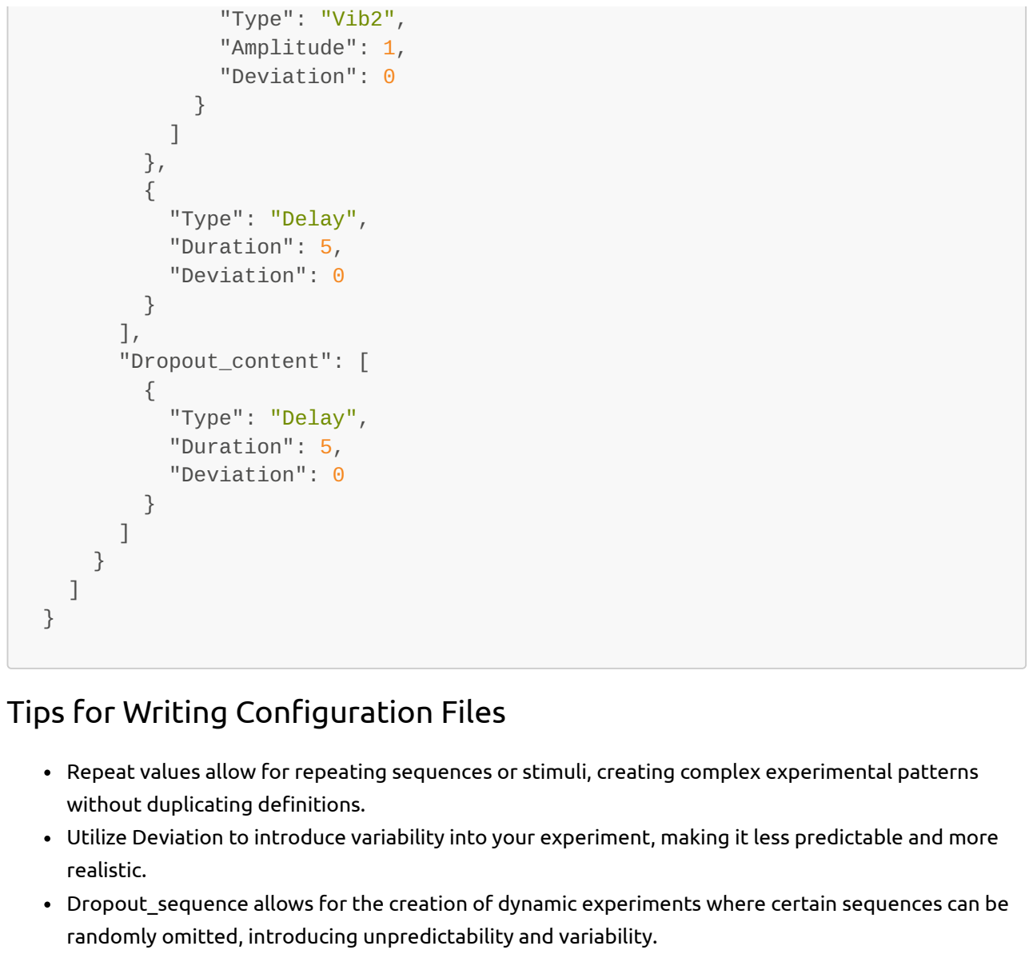
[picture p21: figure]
"Type": "Vib2", "Amplitude": 1, "Deviation": 0; "Type": "Delay", "Duration": 5, "Deviation": 0; } ], "Dropout_content": [ {; Tips for Writing Configuration Files; without duplicating definitions.; realistic.

Repeat values allow for repeating sequences or stimuli, creating complex experimental patterns

Utilize Deviation to introduce variability into your experiment, making it less predictable and more

Dropout_sequence allows for the creation of dynamic experiments where certain sequences can be randomly omitted, introducing unpredictability and variability.

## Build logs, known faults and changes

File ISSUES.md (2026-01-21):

# Known Issues and Limitations

This document tracks bugs, limitations, and potential improvements in the Bsense codebase.

## Critical Issues

### ~~1. Buffer Overflow in Serial Read~~ (FIXED)
**File:** `code/arduino/arduino.ino`, `code/teensy/teensy.ino`
~~**Description:** Serial read doesn't validate `len` before reading into 64-byte buffer.~~
**Fix applied:** Added bounds check `if (len > sizeof(buff))` before reading payload.

### ~~2. Race Conditions in Experiment Thread~~ (FIXED)
**File:** `app/python/core/experiment.py`
~~**Description:** Shared state accessed from multiple threads without synchronization.~~
**Fix applied:** Added `threading.Lock()` protecting `_running`, `_current_idx`, `_sequence`. Made thread daemon with join timeout.

### ~~3. Unvalidated JSON Parsing~~ (FIXED)
**File:** `app/python/core/experiment.py`
~~**Description:** Code assumes JSON fields exist without checking.~~
**Fix applied:** Added field validation with `.get()` for optional fields, `ValueError` exceptions for missing required fields, specific exception handling in `from_json()`.

---

## High Severity

### ~~4. Serial Port Resource Leak~~ (FIXED)
**File:** `app/python/core/arduino_communication.py`
~~**Description:** Previous connection never closed before opening new one.~~
**Fix applied:** Added `disconnect()` method, call it before new connection, catch specific exceptions.

### ~~5. Amplitude Value Overflow~~ (FIXED)
**File:** `app/python/core/arduino_communication.py`
~~**Description:** Amplitude values > 1.0 cause `OverflowError`.~~
**Fix applied:** Clamped values with `max(0, min(255, signal[1]*255))`.

### ~~6. Division by Zero in Frequency Calculation~~ (FIXED)
**File:** `code/teensy/teensy.ino`
~~**Description:** Division by zero when frequency is 0.~~
**Fix applied:** Added guard `(freqVib1 > 0) ? (1000000 / freqVib1) : 0`.

### ~~7. Flawed Frequency Toggle Logic~~ (FIXED)
**File:** `code/teensy/teensy.ino`
~~**Description:** Using wrong timestamps and potential division by zero in timer handler.~~
**Fix applied:** Added start/end time tracking, proper elapsed time calculation, half_period > 0 guards.

### ~~8. Unhandled File Write Error~~ (FIXED)
**File:** `app/python/ui/main_window.py`
~~**Description:** Log file creation fails silently if directory not writable.~~
**Fix applied:** Wrapped file operations in try-except, gracefully disable logging on error.

---

## Medium Severity

### ~~9. GUI Updates from Worker Thread~~ (FIXED)
**File:** `app/python/ui/main_window.py`
~~**Description:** Tkinter not thread-safe, GUI updates from worker thread.~~
**Fix applied:** Used `after()` to schedule `add_log` and `on_new_event` GUI updates on main thread.

### ~~10. Empty Sequence Index Error~~ (FIXED)
**File:** `app/python/ui/main_window.py`
~~**Description:** `IndexError` if sequence empty or index out of bounds.~~
**Fix applied:** Added bounds check in `_update_treeview_selection()`.

### ~~11. Bare Except Clause~~ (FIXED)
**File:** `app/python/core/experiment.py`
~~**Description:** Catches too many exceptions.~~
**Fix applied:** Now catches `FileNotFoundError`, `json.JSONDecodeError`, `ValueError` specifically.

### ~~12. Non-Daemon Thread Blocks Exit~~ (FIXED)
**File:** `app/python/core/experiment.py`
~~**Description:** Thread prevents Python exit.~~
**Fix applied:** Thread set to `daemon=True`, `join()` has timeout.

### ~~13. Negative Delay Possible~~ (FIXED)
**File:** `app/python/core/experiment.py`
~~**Description:** Deviation could cause negative delay.~~
**Fix applied:** Added `dt = max(0, dt)` clamping.

### ~~14. micros() Overflow After ~70 Minutes~~ (FIXED)
**File:** `code/arduino/arduino.ino`
~~**Description:** Timing comparisons fail after overflow.~~
**Fix applied:** Changed to `(t_us - start_time) >= duration` pattern with separate start/duration variables.

### ~~15. Blocking Serial Read~~ (FIXED)
**File:** `code/arduino/arduino.ino`, `code/teensy/teensy.ino`
~~**Description:** Serial.readBytes blocks indefinitely.~~
**Fix applied:** Added 100ms timeout with `millis()` check before reading payload.

### ~~16. No Message Length Validation~~ (FIXED)
**File:** `code/arduino/arduino.ino`, `code/teensy/teensy.ino`
~~**Description:** No validation of expected message length per command.~~
**Fix applied:** Added expected length validation (5 for v/w/b, 10 for c) before processing.

### ~~17. Unvalidated Signal Format~~ (FIXED)
**File:** `app/python/core/arduino_communication.py`
~~**Description:** Assumes tuple structure without checking.~~
**Fix applied:** Added validation for signal type, tuple length, and element count per command type.

---

## Low Severity

### ~~18. Hardcoded COM3 Port~~ (FIXED)
**File:** `app/python/ui/main_window.py`
~~**Description:** Default "COM3" fails on Linux/Mac.~~
**Fix applied:** Platform detection using `sys.platform` - COM3 (Windows), /dev/ttyUSB0 (Linux), /dev/tty.usbmodem* (Mac).

### ~~19. No Connection Retry Logic~~ (FIXED)
**File:** `app/python/core/arduino_communication.py`
~~**Description:** Single failed connection attempt exits immediately.~~
**Fix applied:** Added `retries` and `retry_delay` parameters with exponential backoff (default: 3 retries).

### ~~20. Print Statements Instead of Logging~~ (FIXED)
**File:** `app/python/core/arduino_communication.py`, `app/python/ui/main_window.py`, `app/python/main.py`
~~**Description:** Debug output goes to stderr, not captured in log files.~~
**Fix applied:** Replaced all print() with logging module. Configured in main.py with DEBUG level when -d flag used.

### ~~21. Duplicate Import~~ (FIXED)
**File:** `app/python/ui/main_window.py`
~~**Description:** `import tkinter as tk` appears twice.~~
**Fix applied:** Removed duplicate imports, cleaned up import section.

---

## Design Limitations

### ~~22. No Graceful Shutdown~~ (FIXED)
~~Stimulus continues for full duration after stop is called. Worker thread may be blocked in `time.sleep()`.~~
**Fix applied:** Replaced `time.sleep()` with `threading.Event.wait()` for interruptible delays. Stop/pause immediately interrupts any ongoing delay.

### ~~23. No Connection Monitoring~~ (FIXED)
~~After initial connection, disconnected cable causes silent failures with no user feedback.~~
**Fix applied:** Added `is_connected()` and `check_connection()` methods. UI monitors connection every 1 second, shows error on disconnect, and stops experiment automatically.

### ~~24. No JSON Schema Validation~~ (FIXED)
~~Custom experiment files not validated on load - errors only appear during playback.~~
**Fix applied:** Added `__validate_schema()` and `__validate_stimulus_item()` methods that recursively validate JSON structure on load. Errors include path information (e.g., "root.Content[2].Duration").

### ~~25. Empty Test Suite~~ (FIXED)
~~Test files in `app/python/tests/` are stubs with no actual tests.~~
**Fix applied:** Added 33 unit tests covering schema validation, signal encoding, connection state, and experiment control. Run with `python -m unittest discover tests/`.

---

## Feature Requests

### ~~Extended Frequency Range~~ (IMPLEMENTED)
~~Current protocol limits frequency to 1 byte (0-255 Hz). Audio frequencies need 2 bytes to support full audible range (20-20000 Hz).~~

Protocol now uses 2-byte frequency (0-65535 Hz) for all commands.

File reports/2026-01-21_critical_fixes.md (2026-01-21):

# Critical Bug Fixes Report
**Date:** 2026-01-21
**Author:** Claude Code

## Summary

Fixed 3 critical issues and implemented extended frequency range support for the serial protocol.

---

## Changes Made

### 1. Extended Frequency Range (Feature)

**Problem:** Audio frequency was limited to 1 byte (0-255 Hz), insufficient for audible range (20-20000 Hz).

**Solution:** Extended frequency to 2 bytes (uint16, 0-65535 Hz) across the entire protocol.

**Files Modified:**
- `app/python/core/arduino_communication.py` - Encode frequency as 2 bytes little-endian
- `code/arduino/arduino.ino` - Parse 2-byte frequency, use `tone()` for proper audio generation
- `code/teensy/teensy.ino` - Parse 2-byte frequency with division-by-zero protection
- `CLAUDE.md` - Updated protocol documentation

**New Protocol Format:**
```
Commands (5 bytes payload):
  'v'/'w'/'b': [amp:1] [freq:2] [duration:2]

Combined (10 bytes payload):
  'c': [ampV:1] [freqV:2] [durV:2] [ampB:1] [freqB:2] [durB:2]
```

---

### 2. Buffer Overflow Fix (Critical)

**Problem:** Serial read didn't validate message length before reading into 64-byte buffer. Malformed packets with `len > 64` caused buffer overflow.

**Solution:** Added bounds check before reading payload.

**Files Modified:**
- `code/arduino/arduino.ino:134-139`
- `code/teensy/teensy.ino:144-149`

**Code Added:**
```cpp
if (len > sizeof(buff)) {
    while (Serial.available()) Serial.read(); // flush invalid data
    return;
}
```

---

### 3. Race Condition Fix (Critical)

**Problem:** `self.running`, `self.current_idx`, and `self.sequence` were accessed from multiple threads (UI and worker) without synchronization, causing potential data corruption.

**Solution:**
- Added `threading.Lock()` to protect all shared state
- Implemented thread-safe properties for `running`, `current_idx`, `sequence`
- Made worker thread a daemon with `join(timeout=2.0)`
- Copy sequence before iteration in main loop

**File Modified:** `app/python/core/experiment.py:26-95`

---

### 4. JSON Validation Fix (Critical)

**Problem:** JSON parsing assumed all fields existed without validation. Missing fields caused `KeyError` at runtime. Bare `except:` clause caught `KeyboardInterrupt` and `SystemExit`.

**Solution:**
- Added validation for required fields with descriptive `ValueError` messages
- Used `.get()` with defaults for optional fields
- Replaced bare `except:` with specific exception types
- Added `max(0, dt)` to prevent negative delays

**File Modified:** `app/python/core/experiment.py:96-220`

**Validation Added For:**
| Type | Required Fields |
|---|---|
| Sequence | `Repeat`, `Content` |
| Buzzer | `Amplitude` |
| Vib1/Vib2 | `Amplitude`, `Frequency`, `Duration` |
| BuzzVib1 | `Amplitude_vib1`, `Frequency_vib1`, `Duration_vib1`, `Amplitude_buzz` |
| Delay | `Duration` |
| Dropout_sequence | `Number_drop`, `Repeat`, `Content`, `Dropout_content` |

---

### 5. Amplitude Overflow Fix (High)

**Problem:** Amplitude values > 1.0 caused `OverflowError` when converting to single byte.

**Solution:** Added clamping in `arduino_communication.py`:
```python
amp = int(max(0, min(255, signal[1]*255))).to_bytes(1, ...)
```

**File Modified:** `app/python/core/arduino_communication.py:35-52`

---

## Testing Notes

- **Breaking change:** Firmware must be reflashed for new 2-byte frequency protocol
- Python and firmware changes must be deployed together
- Existing JSON experiment files remain compatible (no schema changes)

---

## Files Changed

| File | Type | Changes |
|---|---|---|
| `app/python/core/arduino_communication.py` | Modified | 2-byte freq, amplitude clamping |
| `app/python/core/experiment.py` | Modified | Thread safety, JSON validation |
| `code/arduino/arduino.ino` | Modified | 2-byte freq, buffer check, tone() |
| `code/teensy/teensy.ino` | Modified | 2-byte freq, buffer check |
| `CLAUDE.md` | Modified | Protocol documentation |
| `ISSUES.md` | Created | Bug tracking document |

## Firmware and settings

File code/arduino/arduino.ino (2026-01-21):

#define TIMER_INTERRUPT_DEBUG 2
#define _TIMERINTERRUPT_LOGLEVEL_ 0
#define USE_TIMER_3 true
#warning Using Timer3

#include "TimerInterrupt.h"

#define TIMER_INTERVAL_MS 1

#define PIN_TRIG 52
#define PIN_VIB1_A 11
#define PIN_VIB1_B 12

#define PIN_VIB2_PWM 14
#define PIN_VIB2_PH 15

#define PIN_BUZZER_TONE 6
#define PIN_BUZZER_AMP 8

#define STARTING_CHAR 0xaa // 170 ascii code: ª

uint8_t ampVib1 = 0;
uint16_t freqVib1 = 0;
uint8_t ampVib2 = 0;
uint16_t freqVib2 = 0;
uint8_t ampBuzz = 0;
uint16_t toneBuzz = 0;
uint16_t timeBuzz = 0;

unsigned long micros_time = 0;
unsigned long start_us_vib1 = 0;
unsigned long duration_us_vib1 = 0;
unsigned long start_us_vib2 = 0;
unsigned long duration_us_vib2 = 0;
unsigned long start_us_buzz = 0;
unsigned long duration_us_buzz = 0;
unsigned long start_us_trig = 0;
unsigned long duration_us_trig = 5000;  // 5ms trigger pulse
bool vib1_state = false;
bool vib2_state = false;
bool buzz_state = false;
bool trig_state = false;

uint8_t source;
uint8_t len;

uint8_t buff[64];
unsigned long t_us = 0;

void TimerHandler()
{
  t_us = micros();

  // Use elapsed time comparisons to handle micros() overflow correctly
  if (vib1_state && (t_us - start_us_vib1) >= duration_us_vib1)
  {
    vib1(false);
  }

  if (vib2_state && (t_us - start_us_vib2) >= duration_us_vib2)
  {
    vib2(false);
  }

  if (buzz_state && (t_us - start_us_buzz) >= duration_us_buzz)
  {
    buzzer(0, 0);
    buzz_state = false;
  }

  if (trig_state && (t_us - start_us_trig) >= duration_us_trig)
  {
    trigger_pulse(false);
  }
}

void vib1(bool state) // switch the vibration1 on or off
{
  digitalWrite(PIN_VIB1_A, state);
  vib1_state = state;
}

void vib2(int amp) // set the vibration2 amplitude and direction
{
  analogWrite(PIN_VIB2_PWM, amp);
  digitalWrite(PIN_VIB2_PH, false);
  vib2_state = amp;
}

void buzzer(int amp, uint16_t freq) // set the buzzer amplitude and frequency
{
  analogWrite(PIN_BUZZER_AMP, amp);
  if (freq > 0 && amp > 0)
  {
    tone(PIN_BUZZER_TONE, freq);
  }
  else
  {
    noTone(PIN_BUZZER_TONE);
  }
  buzz_state = amp;
}

void trigger_pulse(bool state) // trigger a pulse on the trigger pin
{
  digitalWrite(PIN_TRIG, state);
  digitalWrite(LED_BUILTIN, state);
  trig_state = state;
}

void setup()
{
  // Initialize pins
  pinMode(PIN_TRIG, OUTPUT);
  pinMode(PIN_VIB1_A, OUTPUT);
  pinMode(PIN_VIB1_B, OUTPUT);
  digitalWrite(PIN_VIB1_A, LOW);
  digitalWrite(PIN_VIB1_B, LOW);

  pinMode(PIN_VIB2_PWM, OUTPUT);
  pinMode(PIN_VIB2_PH, OUTPUT);

  pinMode(PIN_BUZZER_TONE, OUTPUT);
  pinMode(PIN_BUZZER_AMP, OUTPUT);
  pinMode(LED_BUILTIN, OUTPUT);
  digitalWrite(PIN_BUZZER_AMP, HIGH);

  // Initialize Serial communication and button pin
  Serial.begin(115200);
  delay(100);
  pinMode(LED_BUILTIN, OUTPUT);

  ITimer3.init();
  ITimer3.attachInterruptInterval(TIMER_INTERVAL_MS, TimerHandler);
}

void loop()
{
  if (Serial.available() >= 3)
  {
    Serial.readBytes((char *)&buff, 3);
    if (buff[0] == STARTING_CHAR)
    {
      source = buff[1];                // read what type of stimulus is {v: vibration1, w: vibration2, b: buzzer}
      len = buff[2];                   // read the length of the message
      if (len > sizeof(buff))          // bounds check to prevent buffer overflow
      {
        while (Serial.available()) Serial.read(); // flush invalid data
        return;
      }
      // Wait for remaining data with timeout (non-blocking check)
      unsigned long wait_start = millis();
      while (Serial.available() < len && (millis() - wait_start) < 100) {
        // Brief yield, timeout after 100ms
      }
      if (Serial.available() < len) {
        return; // Timeout - incomplete message, skip
      }
      Serial.readBytes((char *)&buff, len); // read the message

      // Validate message length for each command type
      uint8_t expected_len = 0;
      if (source == 'v' || source == 'w' || source == 'b') expected_len = 5;
      else if (source == 'c') expected_len = 10;
      if (expected_len > 0 && len < expected_len) {
        return; // Invalid message length
      }

      micros_time = micros();          // get the current time
      trigger_pulse(true);             // trigger a pulse on the trigger pin
      start_us_trig = micros_time;     // record start time for trigger
      switch (source)
      {
      case 'v': // trigger a pulse for the vibration1
        ampVib1 = buff[0]; // read the amplitude of the vibration1
        freqVib1 = *((uint16_t *)&buff[1]); // read the frequency (2 bytes)
        vib1(ampVib1);
        start_us_vib1 = micros_time;
        duration_us_vib1 = 100; // the vibration1 pulse is 100us
        break;
      case 'w': // trigger a pulse for the vibration2
        ampVib2 = buff[0]; // read the amplitude of the vibration2
        freqVib2 = *((uint16_t *)&buff[1]); // read the frequency (2 bytes)
        vib2(ampVib2);
        start_us_vib2 = micros_time;
        duration_us_vib2 = 100; // the vibration2 pulse is 100us
        break;
      case 'b': // trigger a pulse for the buzzer
        ampBuzz = buff[0]; // read the amplitude of the buzzer
        toneBuzz = *((uint16_t *)&buff[1]); // read the tone of the buzzer (2 bytes)
        timeBuzz = *((uint16_t *)&buff[3]); // read the duration of the buzzer (ms)
        buzzer(ampBuzz, toneBuzz);
        start_us_buzz = micros_time;
        duration_us_buzz = (unsigned long)timeBuzz * 1000; // convert ms to us
        break;
      case 'c':// combination of Buzzer and Vibration1
        ampVib1 = buff[0]; // read the amplitude of the vibration1
        freqVib1 = *((uint16_t *)&buff[1]); // read the frequency (2 bytes)
        // duration at buff[3-4]
        ampBuzz = buff[5]; // read the amplitude of the buzzer
        toneBuzz = *((uint16_t *)&buff[6]); // read the tone of the buzzer (2 bytes)
        timeBuzz = *((uint16_t *)&buff[8]); // read the duration of the buzzer (ms)
        vib1(ampVib1);
        start_us_vib1 = micros_time;
        duration_us_vib1 = 100; // the vibration1 pulse is 100us
        buzzer(ampBuzz, toneBuzz);
        start_us_buzz = micros_time;
        duration_us_buzz = (unsigned long)timeBuzz * 1000; // convert ms to us
        break;
      default:
        break;
      }
    }
  }
}

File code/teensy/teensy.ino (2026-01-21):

#define TIMER_INTERVAL_US 1000

#define PIN_TRIG 2
#define PIN_VIB1_PWM 0
#define PIN_VIB1_PH 1

#define PIN_VIB2_PWM 2
#define PIN_VIB2_PH 3

#define PIN_BUZZER_TONE 4
#define PIN_BUZZER_AMP 3

#define STARTING_CHAR 0xaa

IntervalTimer myTimer;

uint8_t ampVib1 = 0;
uint32_t periodVib1 = 0;
uint8_t ampVib2 = 0;
uint32_t periodVib2 = 0;
uint8_t ampBuzz = 0;
uint32_t periodBuzz = 0;
uint16_t timeBuzz = 0;

unsigned long micros_time = 0;
unsigned long start_us_vib1 = 0;
unsigned long end_us_vib1 = 0;
unsigned long start_us_vib2 = 0;
unsigned long end_us_vib2 = 0;
unsigned long start_us_buzz = 0;
unsigned long end_us_buzz = 0;
unsigned long delay_trig = 0;
bool vib1_state = false;
bool vib2_state = false;
bool buzz_state = false;

uint8_t source;
uint8_t len;

uint8_t buff[64];
unsigned long t_us = 0;

void TimerHandler()
{
    t_us = micros();

    if (vib1_state)
    {
        if (t_us >= end_us_vib1)
        { // if the duration is over: turn it off
            vib1(0, LOW);
            vib1_state = false;
        }
        else if (periodVib1 > 0)
        {
            // Calculate direction based on elapsed time from start
            unsigned long elapsed = t_us - start_us_vib1;
            unsigned long half_period = periodVib1 / 2;
            bool dir = (half_period > 0) ? ((elapsed / half_period) % 2) : LOW;
            vib1(ampVib1, dir);
        }
    }

    if (vib2_state && t_us >= end_us_vib2)
    { // if the duration is over: turn it off
        vib2(false);
        vib2_state = false;
    }

    if (buzz_state)
    {
        if (t_us >= end_us_buzz)
        { // if the duration is over: turn it off
            buzzer(0, LOW);
            buzz_state = false;
        }
        else if (periodBuzz > 0)
        {
            // Calculate direction based on elapsed time from start
            unsigned long elapsed = t_us - start_us_buzz;
            unsigned long half_period = periodBuzz / 2;
            bool dir = (half_period > 0) ? ((elapsed / half_period) % 2) : LOW;
            buzzer(ampBuzz, dir);
        }
    }

    if (t_us >= delay_trig)
    {
        trigger_pulse(false);
    }
}

void vib1(int amp, bool dir) // switch the vibration1 on or off
{
    analogWrite(PIN_VIB1_PWM, amp * 4);
    digitalWrite(PIN_VIB1_PH, dir);
}

void vib2(int amp) // set the vibration2 amplitude and direction
{
    analogWrite(PIN_VIB2_PWM, amp);
    digitalWrite(PIN_VIB2_PH, false);
    vib2_state = amp;
}

void buzzer(int amp, bool dir) // set the buzzer amplitude and tone
{
    analogWrite(PIN_BUZZER_AMP, amp*4);
    digitalWrite(PIN_BUZZER_TONE, dir);
    buzz_state = amp;
}

void trigger_pulse(bool state) // trigger a pulse on the trigger pin
{
    digitalWrite(PIN_TRIG, state);
    digitalWrite(LED_BUILTIN, state);
}

void setup()
{
    analogWriteResolution(9);
    // Initialize pins
    pinMode(PIN_TRIG, OUTPUT);
    pinMode(PIN_VIB1_PWM, OUTPUT);
    analogWriteFrequency(PIN_VIB1_PWM, 46875);
    pinMode(PIN_VIB1_PH, OUTPUT);

    pinMode(PIN_VIB2_PWM, OUTPUT);
    analogWriteFrequency(PIN_VIB2_PWM, 46875);
    pinMode(PIN_VIB2_PH, OUTPUT);   

    pinMode(PIN_BUZZER_TONE, OUTPUT);
    pinMode(PIN_BUZZER_AMP, OUTPUT);
    pinMode(LED_BUILTIN, OUTPUT);
    digitalWrite(PIN_BUZZER_AMP, HIGH);

    // Initialize Serial communication and button pin
    Serial.begin(115200);
    delay(100);
    pinMode(LED_BUILTIN, OUTPUT);

    myTimer.begin(TimerHandler, TIMER_INTERVAL_US); // start the timer with the handler and interval
}

void loop()
{
    if (Serial.available() >= 3)
    {
        Serial.readBytes((char *)&buff, 3);
        if (buff[0] == STARTING_CHAR)
        {
            source = buff[1];                     // read what type of stimulus is {v: vibration1, w: vibration2, b: buzzer}
            len = buff[2];                        // read the length of the message
            if (len > sizeof(buff))               // bounds check to prevent buffer overflow
            {
                while (Serial.available()) Serial.read(); // flush invalid data
                return;
            }
            // Wait for remaining data with timeout (non-blocking check)
            unsigned long wait_start = millis();
            while (Serial.available() < len && (millis() - wait_start) < 100) {
                // Brief yield, timeout after 100ms
            }
            if (Serial.available() < len) {
                return; // Timeout - incomplete message, skip
            }
            Serial.readBytes((char *)&buff, len); // read the message

            // Validate message length for each command type
            uint8_t expected_len = 0;
            if (source == 'v' || source == 'w' || source == 'b') expected_len = 5;
            else if (source == 'c') expected_len = 10;
            if (expected_len > 0 && len < expected_len) {
                return; // Invalid message length
            }
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

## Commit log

2024-09-24 fixed trigger issue in arduino code
    [arduino.ino, arduino_communication.py, experiment.py]
2026-01-21 Fix critical bugs and extend frequency range to 16-bit
    - Extended serial protocol frequency from 1 byte (0-255 Hz) to 2 bytes
    (0-65535 Hz) to support full audio range
    - Fixed buffer overflow in Arduino/Teensy serial read with bounds check
    - Fixed race conditions in Experiment thread using threading.Lock()
    - Added JSON validation with proper error messages for missing fields
    - Added amplitude clamping to prevent overflow errors
    - Created CLAUDE.md for project documentation
    - Created ISSUES.md to track known bugs and limitations
    BREAKING CHANGE: Firmware must be reflashed for new protocol format.
    Packet lengths changed: v/w/b = 5 bytes, c = 10 bytes.
    [arduino.ino, arduino_communication.py, experiment.py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]
2026-01-21 Fix high severity issues (#4-8)
    - #4 Serial port leak: Added disconnect() method, close existing
    connection before opening new one, catch specific exceptions
    - #5 Amplitude overflow: Already fixed with clamping (verified)
    - #6 Division by zero: Already fixed with freq > 0 guards (verified)
    - #7 Frequency toggle: Fixed timer handler to use proper start/end
    times and elapsed time calculation with half_period guards
    - #8 File write error: Wrapped log file operations in try-except,
    gracefully disable logging on I/O errors
    [arduino_communication.py, teensy.ino]
2026-01-21 Fix medium severity issues (#9-17)
    Python GUI (main_window.py):
    - #9: Thread-safe GUI updates using after() for add_log and on_new_event
    - #10: Bounds check in _update_treeview_selection prevents IndexError
    Python core (already fixed, verified):
    - #11: Specific exception types in from_json()
    - #12: Daemon thread with join timeout
    - #13: Negative delay clamping with max(0, dt)
    Arduino firmware:
    - #14: Fixed micros() overflow using (t_us - start_time) >= duration pattern
    - #15: Added 100ms timeout for serial read to prevent blocking
    - #16: Message length validation (5 for v/w/b, 10 for c)
    Python communication:
    - #17: Signal format validation (type, tuple length, element count)
    [arduino.ino, arduino_communication.py, teensy.ino]
2026-01-21 Fix low severity issues (#18-21)
    - #18: Platform-specific default port (COM3/ttyUSB0/tty.usbmodem)
    - #19: Connection retry with exponential backoff (3 attempts default)
    - #20: Replaced print() with logging module throughout codebase
    - #21: Removed duplicate imports in main_window.py
    Also improved main.py argument parsing and added logging configuration.
    [arduino_communication.py]
2026-01-21 Fix design limitations (#22-25)
    - #22: Replace time.sleep() with threading.Event.wait() for interruptible delays
    - #23: Add connection monitoring with periodic checks and user feedback on disconnect
    - #24: Add JSON schema validation with path-specific error messages
    - #25: Implement 33 unit tests for schema validation, signals, and experiment control
    [arduino_communication.py, experiment.py, test_arduino_communication.py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]
2026-01-21 Add Randomized_sequence and case-insensitive protocol
    - New Randomized_sequence rule type for counterbalanced stimulus presentation
    - Shuffles stimuli with Max_consecutive constraint (no intensity repeats >N times)
    - Optional Label and Delay between stimuli
    - Logs randomized order for reproducibility
    - Protocol now case-insensitive: "type": "sequence" works same as "Type": "Sequence"
    - Added 15 new tests (48 total)
    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
2026-01-30 Fix connection handling and reconnection UI state
    - Remove aggressive periodic connection monitoring (caused device disconnection)
    - Simplify is_connected() to only check is_open flag
    - Add disconnect callback for error-on-send detection
    - Fix greyed play button after reconnection: restore experiment controls
    when subject was already validated
    [arduino_communication.py]
2026-01-30 Add disconnect callback to experiment and fix requirements
    - Add disconnect_cb to Experiment class for UI notification on serial error
    - Handle serial.SerialException specifically for disconnection detection
    - Clean up requirements.txt (remove duplicates, add version constraints)
    [experiment.py]
2026-01-30 Update documentation
    README.md:
    - Update hardware list (Teensy instead of Arduino)
    - Add installation options (pre-built executables + source)
    - Document building with PyInstaller and GitHub Actions
    - Add case-insensitive protocol documentation
    - Document new Randomized_sequence feature with example
    - Update serial protocol (2-byte frequency encoding)
    - Fix MATLAB example code
    - Update config file references
    CLAUDE.md:
    - Update build instructions and file references
2026-01-30 Update Teensy firmware
    - Move firmware to code/teensyScript/
    - Comment out unused VIB2 code
    - Change buzzer to hardware PWM using analogWriteFrequency()
    - Document LRA amplitude scaling (1.8V saturation at ~60% duty)
    - Remove old code/teensy/ directory
    [teensyScript.ino]
2026-01-30 Add changelog and user manual reference to README
    - Add link to userManualGUI.md for detailed protocol documentation
    - Add changelog section documenting v1.1.0 features:
    - Randomized_sequence with Max_consecutive constraint
    - Case-insensitive protocol parsing
    - Cross-platform build infrastructure
    - Improved connection handling
    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
2026-01-30 Add technical documentation, tests, and simulation tools
    - Fix .gitignore (remove duplicate, exclude __pycache__)
    - Add code/tests/audioTest/ - firmware audio/vibration test
    - Add docs images: siggen.png, lrabp.png, sim1-3.png
    - Add reports/: R05jan25 (EEG noise, amplitude mapping), siggen (signal generation)
    - Add simulation/cmd.py - interactive PWM→LRA resonator plot
    - Update README with technical documentation section
    [audioTest.ino, cmd.py]
